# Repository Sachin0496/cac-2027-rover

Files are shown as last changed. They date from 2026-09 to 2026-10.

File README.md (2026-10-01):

# CAC 2027 Rover

Our entry for the Caterpillar Autonomy Challenge 2027 (Shaastra, IIT Madras): a small, light lunar-construction rover with a rotating bucket drum that crosses an
obstacle field, digs sand, carries it and builds a berm, first by remote control and then autonomously.

Start with [`CONTEXT.md`](CONTEXT.md): rules, scoring, strategy, budget, timeline, risks and the 2026-10-01 design review (section 17).

## Repository layout

```
CONTEXT.md        project context, shared by everything below
legacy-v1-v2/     the finished CAD-first designs (v1 and v2): CAD, docs, bill of materials
proto/            (next) the bare, minimal prototype: new work goes here, not in legacy-v1-v2/
firmware/         (next) ESP32 motor / encoder / sensor firmware
ros2_ws/          (next) ROS 2 Jazzy workspace
```

`proto/`, `firmware/` and `ros2_ws/` do not exist yet. Nothing outside `legacy-v1-v2/` depends on it, and nothing in it depends on them.

## Prototype direction

The prototype is deliberately minimal: bare chassis and drive, drum and lift, electronics mounted open, **no hood, side covers or other casings**. Casing was part of
the v2 design (hood, tray cover, side covers, handle); it adds mass and print time and hides the wiring we still need to debug. Add it back only after the
prototype digs, carries and dumps reliably.

## legacy-v1-v2/

Everything built so far lives in one folder so new work cannot tangle with it. Paths inside it are unchanged relative to each other.

| What | Where |
|---|---|
| v2 build guide, print list, mass and load paths | [`legacy-v1-v2/docs/v2-build-guide.md`](legacy-v1-v2/docs/v2-build-guide.md) |
| v2 priced order list and BOM | [`legacy-v1-v2/docs/v2-order-list.md`](legacy-v1-v2/docs/v2-order-list.md), [`legacy-v1-v2/hardware/bom_v2.csv`](legacy-v1-v2/hardware/bom_v2.csv) |
| What changed in v2 and where it departs from the plan | [`legacy-v1-v2/docs/v2-changelog.md`](legacy-v1-v2/docs/v2-changelog.md) |
| v2 parametric CAD (build123d), checks, STLs | `legacy-v1-v2/cad-v2/` |
| v1 CAD (OpenSCAD), build guide, BOM | `legacy-v1-v2/cad/`, [`legacy-v1-v2/docs/v1-build-guide.md`](legacy-v1-v2/docs/v1-build-guide.md), `legacy-v1-v2/hardware/bom.csv` |

### v2 at a glance

Four-wheel skid steer, drum digger on a lift arm. Stowed 601 x 478 x 445 mm, empty 7.94 kg, 74 % of the loaded weight on the front axle, BOM about INR 24.7k
(cap 25,000). It is a parametric Python model with scripted checks for collisions, mass, balance, printing, load paths and the competition rules.

```
cd legacy-v1-v2/cad-v2
uv venv --python 3.12 .venv && source .venv/bin/activate && uv pip install -r requirements.txt
python tasks.py check    # about 15 minutes on a laptop; prints ALL CHECKS PASS
python tasks.py all      # + STEP/STL export (needs FreeCAD), BOM, viewer, pictures, docs
```

`legacy-v1-v2/cad-v2/params.py` holds every dimension. Pictures are in `legacy-v1-v2/docs/img/v2/`.

### Design review, 2026-10-01

Reviewed against the 2027 problem statement. Fixed: the BOM had no wheel encoders (two encoder motors added), the ESP32's Wi-Fi/Bluetooth must be switched
off for the comms inspection, the 5 V converter was under-rated, and the score estimate was about twice too optimistic. See `CONTEXT.md` section 17 for these and
the bench tests still to do (dig depth, camera view, hazard-sensor blind zones, stall currents).

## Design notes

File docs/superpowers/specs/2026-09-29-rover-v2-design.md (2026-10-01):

# CAC 2027 rover v2 — design specification

Date: 2026-09-29 · Branch: `v2` · Status: approved in chat ("do it") and built through drop 3 (tags `v2-drop1` to `v2-drop3`). Where this document and the model disagree, the model wins; §16 is the as-built record and `docs/v2-changelog.md` lists every departure.

## 1. Purpose

Rover v1 (`cad/`, OpenSCAD) is a four-wheel skid-steer rover with a rotating bucket drum on a lift arm, for the Caterpillar Autonomy Challenge (CAC) 2027. v2 keeps that concept and re-engineers everything around it so that the machine

1. looks like a finished product, not a prototype;
2. can be built by students with a college 3D printer and hand tools, without drilling metal;
3. is verified by scripts (collisions, print fit, mass, balance, rules, load paths) instead of by eye.

The mission, rules, strategy, electronics and software plan in `CONTEXT.md` do not change.

## 2. Scope

**In scope:** every printed part; the mounting of every purchased part; the check suite; exports (STEP, STL, glTF, PNG renders, interactive viewer); BOM v2 and order list; build guide v2; v1→v2 change log; an update to `CONTEXT.md`.

**Out of scope:** firmware, ROS 2 and any software; wiring diagrams (only the physical mounting of electronics); URDF or simulation; suspension or tracks; a different motor family; finite-element analysis (hand calculations only); Blender renders; pushing to GitHub (only when the user says so). v1 stays untouched in `cad/`.

## 3. v1 baseline (measured from the repo)

| Fact | v1 |
|---|---|
| Printed part types (`cad/print.scad`) | 30 (the build guide says 29) |
| Printed mass (v1 `export.py` formula) | 2.57 kg |
| Heaviest single print | drum body, 490 g, about 20 h (≈ 25 g/h) |
| Metal to cut and drill | 4 tube lengths, about 30 holes, plus a cut plywood deck |
| Heat-set inserts | about 30 |
| Lift | 9 printed pieces plus an M8 rod with a printed thread |
| Wheel support | on the 6 mm gearbox shafts; outboard bearings optional |
| Front-axle share with a full drum | 80 % |
| Mass on the same accounting as v2 (§9.3) | about 7.0 kg (v1's own table says 7.5 kg: it double-counts the actuator clamp and uses 230 g wheels against 179 g in `export.py`) |
| STEP / FreeCAD | mesh-derived; the drum reports "invalid" in FreeCAD |
| Collision check | part groups, 4 arm poses, mesh based |
| Renders | flat-shaded OpenSCAD |

## 4. Acceptance criteria

"Flawless" means every row below passes at every drop (§11). Rows A1–A11 are enforced by scripts; A12 is a reviewed checklist.

| ID | Criterion | Requirement | Enforced by |
|---|---|---|---|
| A1 | Collisions | No two solids overlap by more than 1 mm³ at arm poses −25°, −20°, 0°, +20°, +35°. Every moving/static pair has at least 2 mm clearance over the whole −25…+35° sweep in 5° steps, except declared running fits (listed in `checks/interference.py` with their designed gap, minimum 0.4 mm). Mating features are modelled with clearance, so there is no allow-list for overlaps. | `checks/interference.py` |
| A2 | Valid solids | Every part is a valid closed solid; the exported STEP re-opens in FreeCAD 1.1 with 0 invalid shapes; every STL is watertight. | `checks/validity.py` |
| A3 | Print fit | Every printed part fits 210 × 210 × 240 mm (usable volume of a 220 × 220 × 250 printer) in its stated print orientation; every downward-facing surface steeper than 45° from vertical (outward normal with n_z below −0.707) either lies on the bed (z under 0.2 mm) or is a bridge whose smallest width is 8 mm or less; any other patch fails. So: no supports anywhere. | `checks/printfit.py` |
| A4 | Print effort | No single print above 180 g (about 7 h at v1's rate; v1's drum body is 490 g). Printed total is reported. | `checks/printfit.py` |
| A5 | Build effort | 0 drilled or tapped holes in metal; 0 heat-set inserts; the only metal cuts are four M4 tie rods to length (hacksaw). Extrusions are cut to length by the vendor (or by hacksaw, ±1 mm is fine). | BOM generator |
| A6 | Mass | Empty mass at most 8.0 kg (limit); goal 7.5 kg. Budget in §9.3. | `checks/massprops.py` |
| A7 | Balance | Front-axle share with a full drum (2.1 kg sand in the drum) at most 75 % (v1: 80 %); expected about 72 %. | `checks/massprops.py` |
| A8 | Rules | Stowed size at the carry pose at most 1500 × 750 × 750 mm; E-stop head at least 40 mm, with a clear approach (100 mm radius) from above, behind and both sides; energy-meter display facing within ±30° of rearward, centre at least 250 mm above ground; three arrow marks on upward-facing surfaces. | `checks/rules.py` |
| A9 | Sensor views | Camera cone (±35° horizontal, ±25° vertical) free of the rover's own parts at pan 0° and 180°; each ToF cone (27° full angle) free at the carry pose. | `checks/rules.py` |
| A10 | Load paths | Safety factor at least 2 at 3× the static load on: wheel housing and bolts, axle, pivot bracket, both arms, lift link, drum tie rods, tray plate (deflection ≤ 1 mm). Inputs and formulas are printed in the build guide. | `calcs.py` |
| A11 | Cost | BOM generated from the model, priced per item; goal ≤ ₹25k including filament (see §12: the estimate is ₹25.2k, so the order list names a cheaper acceptable substitute for the items that would close the gap). | BOM generator |
| A12 | Looks | The visual checklist in §8.4 passes on six fixed views at every drop. | manual review of renders |

## 5. Conventions

- Units mm, degrees, grams. World frame as v1: +X forward (drum end), +Y left, +Z up, ground at z = 0, frame centred on x = y = 0.
- Arm poses: press −25°, dig −20°, level 0°, mid +20°, carry/dump +35° (v1 values).
- Part ids are snake_case with a module prefix: `drv_`, `wheel`, `drum_`, `arm_`, `pivot_`, `lift_`, `tray_`, `batt_`, `tower_`, `hood_`, `body_`, `tof_`. Each part carries metadata: `kind` (printed / purchased / stock), `module`, `qty_per_rover`, `mass_g`, and for purchased parts `price_inr`, `price_basis` (listed / estimate), `source`, `datasheet` (true / measure-first).
- Printed mass = solid volume × 1.27 g/cm³ (PETG) × 0.75 (v1's factor for 3–4 walls and 25 % gyroid), so v2 and v1 are comparable.

## 6. Layout

All values live in `cad-v2/params.py`. Initial values below; constraints are enforced by the checks.

| Parameter | Initial value | Note |
|---|---|---|
| Wheel | Ø174 mm over grousers × 60 mm, 14 grousers | unchanged, so v1's sand-pit plan and numbers carry over |
| Track (wheel centre to centre) / wheelbase | 380 mm / 300 mm (axles at x = ±150, height 87 mm) | unchanged; overall width 440 mm |
| Rails | 2020 T-slot (20 × 20 mm, slot 6 mm, M5), centre line y = ±140 mm, z = 116…136 mm, x = −210…+170 mm (380 mm long) | if the front-corner clash below needs it, the rails rise by the smallest amount (expected ≤ 8 mm) |
| Cross members | 260 mm, butted between the rails; rear at x = −185, front at x = pivot_x − 65 (clears the arm roots by at least 5 mm at every pose) | joined with two inside corner brackets per joint |
| Arm pivot | pivot_x = 159 mm, z = 126 mm (v1: 199 mm) | 40 mm back gives about 72 % front-axle share on the §9.3 mass table (D4). The layout script keeps the largest shift between 20 mm (74 %) and 40 mm (72 %) for which the front-corner clash below is resolved by raising the rails by no more than 8 mm |
| Arm length, drum | 130 mm pivot to drum axis; drum shell Ø160, tooth tips Ø180, length 200 mm | unchanged |
| Lift | stroke at least 83 mm; T8×2 screw axis on the centre line, 155 mm above ground | |
| Tower | 2020 post 300 mm above the tray plate; overall height at most 620 mm (v1: 581 mm) | |
| Ground clearance | at least 60 mm under motors and mounts on firm ground | v1: about 70 mm |

**Front-corner clash (known):** with the pivot 40 mm back, the arm root at the front rail overlaps the front drive motor's gearbox by about 5 mm in z. The layout script resolves it by raising `rail_z0` (and with it the pivot) by the smallest amount that gives 5 mm clearance at every pose. If that needs more than 8 mm, the script reduces the pivot shift toward 20 mm; if 20 mm is still not enough, the fallback in §13 applies.

## 7. Modules

Six modules, each buildable and testable on its own. Mounting to the chassis is always M5 through round holes into spring T-nuts, with the printed part clamping on flat extrusion faces (nothing engages the slot), so slot differences between vendors do not matter.

### 7.1 Chassis (`modules/chassis.py`)

- **Stock (2020 T-slot, buy 2 × 1 m):** piece A = 380 + 380 + 232 mm (two rails, arm crossbar); piece B = 260 + 260 + 300 mm (two cross members, tower post). Total 1 812 mm.
- **Hardware:** 8 inside corner brackets (2 per joint), about 60 spring T-nuts M5, M5 button-head screws (10, 12 and 16 mm).
- **No plywood deck.** The electronics tray and the hood are the mounting surface.
- **Faces:** top slots carry tray, hood, battery cradle and tower base; outer slots carry the drive mounts; bottom slots carry the motor cradles; inner slots carry the pivot brackets.

### 7.2 Drive module ×4, identical (`modules/drive.py`)

Wheel loads go into two bearings; the motor shaft carries torque only.

- **Purchased (per module):** Johnson 12 V ~30 RPM side-shaft motor; 2 × 608 bearing; M8 × 80 hex bolt (axle); M8 nyloc nut and 2 washers; flexible jaw coupler 6→8 mm (Ø20 × 25 mm); 4 × M5 + T-nut (mount and cradle to rail); M4 bolts and nuts for the cradle.
- **Printed:** `drv_mount` (plate on the rail's outer face, with a two-bearing housing that reaches into the wheel's open inner side), `drv_cradle_roof`, `drv_cradle_cap`, `axle_spacer` (2 per module, one part type), `wheel` (hub and hex pocket for the bolt head are part of the wheel print; 165 g target, v1: 179 g).
- **Axle stack, outboard to inboard:** wheel (bolt head in the hex pocket) → outer spacer → bearing A → housing web → bearing B → inner spacer → washer and nyloc nut → flexible coupler → motor shaft. Tightening the nut clamps the bolt, wheel and both inner races into one rotating body; the housing shoulders and a printed retainer hold the outer races.
- **Motor position:** the gearbox axis sits 7.5 mm above the shaft (v1 convention; parameter `jm_shaft_off`, 0 for a centre-shaft motor). The cradle bolts to the mount through slotted M4 holes (±1.5 mm) so the shaft and axle can be aligned by eye with a straightedge; the coupler absorbs the rest.
- **Why:** a sideways skid loads the shaft through a wheel radius of 87 mm. On the gearbox bushing (span about 10 mm) that is roughly three times the reaction force of a 30 mm bearing span, and it is the failure mode v1's own guide worries about. Any motor with a 6 mm shaft also fits by sliding the cradle, which removes v1's dependence on unmeasured motor dimensions.

### 7.3 Excavator (`modules/excavator.py`, `modules/lift.py`)

- **Drum:** four rings of 48 mm between two 4 mm end plates (200 mm), shell 2.0 mm, four scoops per ring with the v1 baffle spiral (sweep 150°, core Ø52). Two ring designs, `drum_ring_a` and `drum_ring_b` (teeth rotated 45°), stacked A, B, A, B, so one tooth cuts at a time as in v1. Each ring has four external lugs at fixed angles (between the teeth, inside the tooth-tip envelope); four M4 tie rods (threaded rod cut to about 215 mm) clamp the stack with 8 nyloc nuts. End faces have a 2 mm spigot and recess for concentricity. Each ring is about 120 g (v1's one-piece body is 490 g).
- **End plates:** `drum_plate_drive` has a hex pocket for the M8 bolt head and a boss (the drum is driven through the same axle kit as the wheels); `drum_plate_idler` has a 608 pocket.
- **Arms:** `arm_drive` (left) carries the drum motor cradle and a boss with two 608 bearings; `arm_idler` (right) carries the idler bolt (M8 × 50, dead axle). Each arm has an integral square socket that clamps the 2020 crossbar (two M4 pinch bolts with nut traps) — no drilling. The arm root has a 608 bearing on an M8 × 50 pivot bolt held by `pivot_bracket_l` / `pivot_bracket_r`, which clamp on the rails' inner faces.
- **Lift:** T8 lead screw, single start, 2 mm lead (self-locking at a friction coefficient of 0.10 or more; dry brass on steel is 0.15–0.20), brass flange nut in `lift_carriage`, two identical `lift_bearing_block` (608), `lift_channel` (guide), `lift_cradle_roof` / `lift_cradle_cap` for a Johnson 300 RPM motor, the same flexible 6→8 mm coupler as the wheels, two micro limit switches, `lever` (clamped on the crossbar centre) and one `lift_link` (M5 pins). About 10 mm/s at 300 RPM. v1's two pushrods are replaced by one link on the centre line. At each arm pose the carriage position follows from the link length and lever geometry (closed form, as v1's `carriage_x`); the assembly builder derives it, and `interference.py` fails if the carriage would leave the screw's travel or the limit-switch positions.
- **Drum test jig (no new parts):** arms + crossbar + drum + drum motor on a 1 m length of T-slot as a handle; the build guide describes it for v1's "drum on a stick" test.

### 7.4 Electronics tray (`modules/electronics.py`)

- One removable **U-shaped tray** that rests on the rails and nests around the lift screw. Printed in three pieces (`tray_left`, `tray_right`, each at most 120 × 200 mm, and `tray_tie` behind the lift motor), joined by M4 bolts into one rigid unit before wiring. 3 mm plate with 6 mm ribs.
- **Left bay (power):** 4 × BTS7960 drivers, relay/contactor, main fuse and branch fuses, 5 V buck. **Right bay (compute):** Raspberry Pi 5 with cooler, ESP32, MPU6050, connectors to sensors and servo. A cable channel behind the lift motor joins the bays.
- **Battery cradle** (`batt_cradle`, strapped) on the rear cross member; default pack model 70 × 60 × 40 mm, ±3 mm adjustable.
- Every board sits on printed standoffs with slotted holes (±3 mm) so measured sizes can differ from the datasheet.

### 7.5 Sensor tower (`modules/tower.py`)

- 2020 post on the rear cross member with `tower_base` (4 × M5). Two-half cladding (`tower_sleeve_lower`, `tower_sleeve_upper`, wall 2 mm) hides the post and the cables.
- **Top:** `tower_camera_head` — USB webcam on an SG90 pan servo (0°/180°). **Side shelf below the camera line:** `tower_estop_shelf` — 22 mm panel-mount E-stop, modelled with a Ø60 mm head (any ≥ 40 mm head fits), set to the side so it never blocks the camera at either pan angle. **Rear face:** `tower_pzem_housing` — PZEM-051 display window facing back, high and visible. **Base:** `tof_rear_mount` (rear-looking ToF, 35° down).

### 7.6 Body (`modules/body.py`)

- Vented **hood** over the tray (about 200 × 300 mm) with a raised spine over the lift screw, in three panels printed upside down: `hood_left` and `hood_right` (105 mm wide) and `hood_spine` (90 mm wide), each at most 200 mm long, with the end walls built in. Seams are deliberate panel lines with a 0.6 mm reveal, never within 5 mm of a vent. Louvers face down and back to keep sand out; overlapping lips seal the seams. Fixed to the tray with M4 button screws.
- **Side covers** over the rails between the wheels (`body_side_cover`, mirrored), **ToF noses** (`tof_nose_l`, `tof_nose_r`) on the pivot brackets, one **carry handle** (`body_handle`, a bridge over the spine at the empty-mass centre of gravity, 30 mm hand clearance, bolted through the hood into the tray).
- **Three arrow marks**, each a 90 × 30 mm recess 0.8 mm deep on an upward-facing surface: forward on the front of the spine (pointing +x), length on `hood_left` (double-headed along x), width on the rear of the spine (double-headed along y). The size is an assumption; the rules digest gives none.

## 8. Design language

### 8.1 Colour by function

| Group | Colour | Used for |
|---|---|---|
| Working parts | CAT yellow `#FFCD11` | drum, arms, hood, tower head |
| Structure and drive | graphite `#2B2E33` | wheels, mounts, cradles, covers, trays, tower sleeves |
| Frame | natural aluminium `#C9CDD2` | 2020 extrusions |
| Hardware | steel `#8A8F98`, brass `#B5A642` | bolts, nuts, screw and nut |
| Electronics | black `#1A1A1A` | boards, motors, servo, camera |
| Safety | red `#D7191C` | E-stop only |

Colours are parameters in `params.py`; changing them regenerates everything.

### 8.2 Geometry rules

- External radius 3 mm on visible edges, 1.5 mm on small parts, 0.4 mm chamfer where a part meets the bed (elephant foot), 0.6 mm reveal between panels.
- Fastener heads sit in counterbores or hex pockets; no protruding nuts on visible faces; wiring hidden under the hood or in channels.
- The hood and tower share one vent-slot pattern on a 6 mm grid.
- Overhangs are designed in (45° chamfers, teardrop holes, stepped bridges), not left to supports.

### 8.3 Fastener policy

- Frame and mounts: M5 button head into spring T-nuts.
- Printed-to-printed: M4 socket or button head with a nut in a printed hex trap. **No heat-set inserts.**
- Pivots and axles: M8 bolts with nyloc nuts (the smooth shank runs in the bearings).
- Small parts (sensors, covers, switches): M3 with nut traps; self-tapping screws only for non-structural covers.
- Tools for assembly: 2.5, 3 and 4 mm hex keys and one 13 mm spanner (M8 bolts and nuts).

### 8.4 Visual review checklist (A12)

Six fixed views: front-left ¾, rear-right ¾, side at dig pose, front, top, exploded. Each drop must show: no floating or intersecting parts; all panel reveals equal; radii consistent; colours follow §8.1; no bolt sticking out of a visible face; E-stop, energy meter and camera each visible from at least one view; wheels and drum read as one family with the body.

## 9. Verification

Run with one command (`python tasks.py check`); a drop ships only when all checks pass.

### 9.1 Checks

- **`interference.py` (A1):** build the assembly at each pose; bounding-box prefilter, then exact boolean intersection volume for every candidate pair. Moving parts are the arm assembly (arms, drum, drum motor, crossbar, lever), the lift carriage and the link; wheels and the drum are checked as their swept cylinders (grouser-tip and tooth-tip radius). For the sweep, sample points on moving parts and measure the minimum distance to static parts.
- **`validity.py` (A2):** `is_valid` on every part; export the STEP; re-import it headless in FreeCAD 1.1 (`freecadcmd`) and check every shape; check each STL with trimesh for watertightness.
- **`printfit.py` (A3, A4):** place each part in its declared print orientation (`ORIENT` table), then check bounding box, downward-facing triangle areas past 45°, bridge spans, and mass by the §5 formula.
- **`massprops.py` (A6, A7):** mass and centre of gravity of the whole rover, empty and with 2.1 kg of sand at the drum centre, at the carry pose; front-axle share; overall size.
- **`rules.py` (A8, A9):** the geometric rules and cone checks in §4.
- **`calcs.py` (A10):** closed-form checks with the inputs printed. Loads: 3× the worst static wheel load (front axle at 75 %), lateral skid force 0.6 × vertical, drum reaction 60 N horizontal plus 40 N vertical at a tooth tip, the lift link force at the press pose. Material: PETG design stress 20 MPa along layers and 10 MPa across layers; steel bolts by class; brass and aluminium nominal.
- **`tests/`:** pytest on synthetic shapes proves each check catches what it should (an overlapping box pair, a 60° overhang, an oversize part, an unbalanced mass).

### 9.2 Fit-test kit (about 30 min print)

One STL that carries: three 608 seats (22.0, 22.1, 22.2 mm), M4 and M5 nut traps at three clearances, an M8 hex pocket (13 mm across flats) at three clearances, a hole set (M3, M4, M5, M8 at three clearances), and a 20 mm slice of the motor cradle. The user prints it first and sets three numbers in `params.py`: `tol_bearing`, `tol_trap`, `tol_hole`. Nothing large is printed before that.

### 9.3 Mass accounting and budget (grams, empty)

Printed parts by the §5 formula; purchased parts by datasheet or typical weight. v1 is recomputed on the same basis. Targets are for the drop-3 report.

| Item | v1 | v2 budget |
|---|---|---|
| Chassis extrusions and brackets (v1: tube and plywood deck) | 792 | 700 |
| Drive modules ×4, without motor and wheel | 344 | 820 |
| Wheels ×4 | 716 | 660 |
| Drive motors ×4 | 1 120 | 1 120 |
| Excavator without motor (drum, arms, pivots, crossbar, lever, hardware) | 1 057 | 1 111 |
| Drum motor | 280 | 280 |
| Lift (motor, screw drive, printed parts, link, switches) | 540 | 559 |
| Electronics boards and connectors | 390 | 390 |
| Tray and battery cradle | 247 | 240 |
| Battery pack | 250 | 250 |
| Sensor tower (post, cladding, E-stop, PZEM, camera, servo, ToF) | 653 | 699 |
| Body (hood, side covers, handle, ToF noses) | 0 | 410 |
| Wiring | 250 | 250 |
| Fasteners | 350 | 250 |
| **Total** | **≈ 6 990** | **≈ 7 740** |

The v2 budget is about 0.75 kg (11 %) above v1, which costs roughly a tenth of the mass-score component. The drivers are the bearing-supported drive modules (+0.48 kg) and the body (+0.41 kg). Goal 7.5 kg needs about 0.24 kg of lightweighting in drop 3 (thinner hood walls, lighter wheel spokes, lighter tower sleeves, lighter tray ribs); the hard limit is 8.0 kg.

v2 also prints more than v1: about 3.1 kg in roughly 40 part types (v1: 2.57 kg, 30 types), because of the hood, the tower cladding and the drive housings. Each new part is small; none exceeds 180 g, and the longest print falls from about 20 h to about 7 h.

## 10. Toolchain and repository layout

**build123d** (free Python library on the OpenCascade kernel that FreeCAD also uses), in a virtual environment inside `cad-v2/` (Python 3.12, a few hundred MB, nothing installed system-wide). Dependencies are pinned in `pyproject.toml` and mirrored in `requirements.txt`; `numpy`, `scipy`, `trimesh`, `pytest` for the checks. FreeCAD 1.1.3 (already installed; `/Applications/FreeCAD.app/Contents/Resources/bin/freecadcmd`) is used only to validate the STEP; Chrome (already installed) renders images headlessly.

```
cad-v2/
  pyproject.toml  requirements.txt  tasks.py     # tasks.py: check | export | render | all
  params.py                # every shared dimension, colour, tolerance
  lib/     profile2020.py  cots.py  fasteners.py  style.py
  modules/ chassis.py  drive.py  excavator.py  lift.py  electronics.py  tower.py  body.py
  assemble.py              # rover(pose) -> named, coloured, metadata-carrying compound
  checks/  interference.py  validity.py  printfit.py  massprops.py  rules.py
  calcs.py
  export.py                # STEP, STL in print orientation, glTF, BOM (json and csv)
  render/  viewer.html  render.py
  tests/
  out/                     # generated: rover_v2.step, stl/, rover_v2.glb
docs/v2-build-guide.md  docs/v2-order-list.md  docs/v2-changelog.md  docs/img/v2/
hardware/bom_v2.csv
```

To change a dimension: edit `params.py`, run `python tasks.py all`. The STEP, STLs, BOM, renders and checks all regenerate.

## 11. Deliverables and drops

Each drop is committed on branch `v2` and tagged (`v2-drop1`, `v2-drop2`, `v2-drop3`); all applicable checks pass before the tag.

| Drop | Contents | Why this order |
|---|---|---|
| **1 — mobility kit and order list** | The tooling (params, lib, checks, tests, export, render); chassis, four drive modules, four wheels; the fit-test kit; `hardware/bom_v2.csv` and `docs/v2-order-list.md` covering every purchased part whose spec is fixed by then (extrusions with cut lengths, motors, bearings, couplers, bolts, T-nuts, T8 screw, brass nuts) | The team orders parts around 5 Oct and the chassis must drive on sand around 20 Oct. |
| **2 — excavator** | Drum rings and plates, arms, pivot brackets, crossbar, lever, lift module; the balance study with the real model; calcs for arms, lift and drum; renders of dig, carry and dump; drum test-jig instructions | The drum print and pit test are the biggest unknown and come first. |
| **3 — electronics, tower, body, documents** | Trays, battery cradle, tower, hood, covers, handle, arrows, ToF noses; all checks on the full assembly; lightweighting pass; six fixed renders and an exploded view; the interactive viewer; final BOM; build guide; change log; `CONTEXT.md` update | Everything left, and the look is judged on the finished machine. |

Fastener counts in the order list are final at drop 3; the order list advises buying an assortment with 20 % spare until then.

**Planning:** one implementation plan per drop. The drop-2 and drop-3 plans are written after the previous drop's checks pass, because they depend on its geometry (for example how the front-corner clash resolves).

## 12. BOM and budget

Estimates use v1's sources and price basis (Indian store listings, 2026-09-28) for unchanged items; new items are estimates until priced during drop 1.

| Change against v1 | ₹ |
|---|---|
| Frame: T-slot 2 m (900), brackets (200), 60 spring T-nuts (480), M5 screws (120), minus tube and plywood (−800) | +900 |
| Drive modules: 10 more 608 bearings (350), six flexible couplers at ₹200 less v1's one rigid coupler at ₹100 (1 100), M8 × 80 axle bolts, nuts, washers (150) | +1 600 |
| Lift: T8×2 screw and brass flange nut in place of the M8 rod | +250 |
| Drum tie rods and nyloc nuts | +120 |
| No heat-set inserts | −300 |
| Filament 3.5 kg in place of 3 kg | +500 |
| **v1 ₹22 120 → v2** | **≈ ₹25 200** |

Excluding filament (the college may supply it) v2 is about ₹21 700. Substitutes that recover about ₹1 200 if needed: rigid couplers on the wheel axles (−₹400), less spare stock (−₹500), cheaper T-slot supplier (−₹300).

## 13. Risks, measure-first gates and fallbacks

| Risk | Mitigation or fallback |
|---|---|
| **M1: motor dimensions unmeasured** | Measure one Johnson motor before printing `drv_cradle_*`, `arm_*` motor cradles and `lift_cradle_*`; the fit-test kit includes a cradle slice; cradles slide ±1.5 mm. Fallback: motor family is a parameter block (`jm_*`). |
| **M2: sizes of PZEM-051, relay, buck, BTS7960, E-stop body and battery are unpublished or vary** | Defaults in `cots.py`; holders adjustable ±3 mm; measure when the parts arrive and update `params.py`. |
| Extrusion profile varies between vendors | Printed parts clamp on flat faces only; M5 through round holes into T-nuts. |
| Print tolerance varies between printers | Fit-test kit (§9.2). |
| Front-corner clash (arm root against front motor) | Raise the rails (≤ 8 mm). If more is needed: flip the motor offset on the front modules (ground clearance 60 mm) or lengthen the wheelbase to at most 340 mm (front axle forward); either is raised with the user first. |
| Balance target of 75 % not reachable | Report the achieved value; consider the wheelbase fallback above; no ballast (mass costs score). |
| Mass above 7.5 kg | Lightweighting list in drop 3; the user decides whether the 8.0 kg limit moves. |
| Lift screw back-drives (T8×2 is self-locking only above μ ≈ 0.09) | Lubricate; use the driver's brake mode; or fall back to v1's M8 rod with a printed nut. |
| build123d fillet or boolean failures | Build with simple operations; fillet before booleans; fall back to chamfers; per-feature try/except in the build so the failing feature is named. |
| Sand performance and drum torque | Not provable in CAD: the same measure-first pit tests as v1 (drum on a stick first). |

## 14. Decision log

| # | Decision | Reason | Rejected |
|---|---|---|---|
| D1 | Same concept: drum digger, four-wheel skid steer, same electronics | The user chose it; nothing to test a new concept against before the 10 Nov video | Polish only (capped by OpenSCAD); clean-sheet concept |
| D2 | 2020 T-slot frame with spring T-nuts, no plywood | No drilling; adjustable; hides vendor variation | 20 × 20 tube with drilled holes (about 0.3 kg lighter, harder to build) |
| D3 | Two-bearing axle module with flexible coupler for wheels and drum drive | Removes the sideways-skid load from the gearbox bushing and the dependence on motor dimensions | Wheels on gearbox shafts as in v1 (about 0.3 kg and ₹1 100 cheaper) |
| D4 | Arm pivot 20–40 mm back, battery and tower rearmost | Balance study on the §9.3 mass table (estimated positions): loaded front-axle share 77 % with no shift, 74 % at 20 mm, 73 % at 30 mm, 72 % at 40 mm, 70 % at 60 mm (v1: 80 %). The estimate is good to a few points, so the requirement is 75 % with about 72 % expected; the model's own mass report replaces the study at drop 2. | Ballast (mass costs score); a longer wheelbase (kept as a fallback) |
| D5 | Drum in two ring designs (A/B), four rings, external tie rods | Prints in about 5 h a ring instead of 20 h; a failed ring costs one ring; straight tie rods need fixed lug angles, so two designs rather than four identical rings | Four identical rings with rotating lugs (rods would not align) |
| D6 | T8×2 screw and brass nut, one link | Standard parts replace a printed thread; one link on the centre line | Commercial linear actuator (about ₹2 500 more) |
| D7 | build123d in a project venv | Real solids, fillets, true STEP, exact booleans for the checks | OpenSCAD (mesh STEP, no fillets) |
| D8 | Colour by function, CAT yellow and graphite | One family; the sponsor's colour; parameters | White/silver "lunar" or matte black (still possible: one line) |
| D9 | Pivot brackets clamp on the rail inner faces | Rails cannot be drilled across | Cross-drilled rail as in v1 |
| D10 | U-shaped tray in three pieces | A single tray cannot fit around the lift screw and the 220 mm bed | Two separate trays |

## 15. Assumptions and defaults

- Printer 220 × 220 × 250 mm, PETG, 0.4 mm nozzle; college supplies the printer.
- Hand tools, hex keys, a hacksaw, a soldering iron for electronics; no laser, CNC, lathe or drill press.
- Budget cap ₹25k including filament (`CONTEXT.md` §6); free tools only.
- 2020 T-slot is the B-type, slot 6 mm, M5. Spring T-nuts are M5 drop-in.
- Motor: Johnson 12 V side-shaft, Ø37 × 25 mm gearbox, Ø28.5 × 38 mm can, 6 mm D shaft (22 mm long, 5.5 mm across the flat), shaft offset 7.5 mm (v1 values, measure-first).
- Battery pack 3S2P about 70 × 60 × 40 mm, 250 g (measure-first).
- Arrow marks 90 × 30 mm (the rules digest gives no size).
- E-stop modelled Ø60 mm head, 22 mm panel-mount.
- Nothing is pushed to GitHub, and no artifact is published, without the user's explicit OK.

## 16. As built (2026-09-29)

All three drops are done; `python tasks.py check` prints ALL CHECKS PASS and the 120 tests pass.

| ID | Result |
|---|---|
| A1 | 0 collisions at the five poses (-28, -25, 0, +20, +35); 2 mm clearance moving-vs-static at eight poses from -28 to +35; no floating or half-held fastener (contact-graph check) |
| A2 | STEP re-opens in FreeCAD 1.1 with 438 solids and 0 invalid shapes; 44 STLs, all watertight |
| A3, A4 | every part fits 210 x 210 x 240 mm and prints without supports; largest print 137 g (limit 180); printed total 2.55 kg in 43 part types |
| A5 | 0 drilled or tapped holes, 0 heat-set inserts; the only cuts are the 2020 (three 1 m bars), one M4 rod (four tie rods) and one M8 rod (the lift screw) |
| A6 | 7.94 kg empty including the 250 g wiring allowance: inside the 8.0 kg limit, 0.44 kg over the 7.5 kg goal |
| A7 | front-axle share 74.1 % with 2.1 kg of sand at the carry pose (limit 75 %; v1 80 %); 53 % empty |
| A8 | stowed 601 x 478 x 445 mm; E-stop head 60 mm, reachable from above, behind and outboard; PZEM display faces rearward at 321 mm; three arrow plates on the roof |
| A9 | camera at pan 0 sees only the excavator, at pan 180 nothing; both front ToF cones and the rear cone are free at the carry pose |
| A10 | eleven load paths, lowest safety factor 2.1 (pivot bracket wall); tray plate deflects 0.88 mm at three times the load (limit 1 mm) |
| A11 | INR 23,329 with filament, wiring, sand pit and spares (cap 25,000; v1 22,120); `hardware/bom_v2.csv` |
| A12 | six fixed views plus dig, exploded and hood-off pictures in `docs/img/v2/`; reviewed by the author only, the user's eye is the real test |

Amendments to the decision log: D4's expected 72 % became 74 % (the excavator is heavier than budgeted; the rear axle moved 40 mm forward to compensate); D6 became an M8 x 1.25 rod
with two brass nuts and two link plates; D9's brackets stand on the rail tops instead of clamping on the inner faces; the hood is two halves, not three panels. See `docs/v2-changelog.md`.

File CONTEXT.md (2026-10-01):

# CAC 2027 Rover — Project Context

Single source of truth for the team (and for any AI assistant helping us).
Last updated: **2026-09-29** (v2 CAD added: see §10). Rules below are a summary of the official CAC 2027
problem statement — always check the latest PDF (links in §16) before relying on a number.

---

## 1. The challenge in one paragraph

The **Caterpillar Autonomy Challenge (CAC) 2027** is run by Shaastra (IIT Madras's tech fest)
and sponsored by Caterpillar. The rules are adapted from NASA Lunabotics. We build a
lunar-construction rover that starts at a random pose, crosses an obstacle field in a
sandbox, digs sand in the excavation zone, **carries** it (bulldozing is not allowed) and dumps
it into a berm target. Scoring = berm volume normalised by **robot mass** and **energy used**,
plus large bonuses for **autonomy**.

## 2. Key dates, prizes, team rules

| What | When |
|---|---|
| Registration closes (Unstop, free) | **30 Sep 2026, 00:00 IST** |
| Video round: working rover on sand (non-competitive, required) | 10 Oct – 10 Nov 2026 |
| Prelims at IIT Madras: 1 attempt, 10-min run | 2 Jan 2027 (tentative) |
| Finale: 1 attempt, 7-min setup, 15-min run, 5-min removal | 3 Jan 2027 (tentative) |

- **Prizes (₹3.5 L total):** Winner ₹1.25 L · 1st runner-up ₹95k · 2nd runner-up ₹70k ·
  Best Design ₹30k · Judges' Innovation ₹30k.
- **Team:** 1–12 students, any discipline, any college. Max **4** people in Mission Control
  (MCC) and max **4** in the arena for setup/removal. No faculty in the arena or MCC.
- **2026 results:** Winner Team Algo Steam (Sri Eshwar College of Engineering, also Best Design);
  runner-up Team Anveshak (IIT Madras); 2nd runner-up Team Rodix (KPR Institute).
  The organisers' 2027 resources guide says many 2026 teams **had trouble with mobility**.

## 3. Arena (from the 2027 diagram, which is "for reference only")

- ~9 m × 5 m box, ~30 cm of tilled, dry sand.
- **Start zone** (~2 m, top-left, no obstacles) → **Obstacle zone** (~5.5 m) →
  **Excavation zone** (~1.5 m wide strip at the far end).
- **Construction zone** ~2 m × 1.5 m at the bottom-left, next to the start zone;
  **berm target 1.25 m × 0.9 m**. ⇒ Every dig→dump cycle crosses the obstacle zone **twice**.
- Obstacle zone: **≥3 boulders** (30–40 cm diameter, random heights) and **≥3 craters**
  (up to 40–50 cm wide). Smaller boulders may also be in the excavation zone.
- Start position and heading are random (judges spin N/S/E/W). The robot must carry 3 marked
  arrows: length, width and a "forward" reference.

## 4. Robot rules that shape our design

- **Size/mass:** stowed ≤ 1.5 × 0.75 × 0.75 m (may deploy up to +1.75 m in height after the
  start). ≤ 80 kg including any beacons.
- **Banned:** GPS; compass/magnetometer (must be disabled and explained to judges); ultrasonic
  sensors; touch/bump sensors; pneumatic rubber tyres; air- or foam-filled tyres; hydraulics.
  Closed pneumatics only if fully self-contained.
- **No walls:** the robot must not use arena walls for sensing, mapping or collision avoidance,
  and we must prove it. Not disclosing the autonomy sensing method = disqualification.
- **No line-of-sight driving (new in 2027):** operators may only use data/video from the robot
  and the competition monitors.
- **Sand:** only from the excavation zone; must be carried (a small lift is enough). Don't touch
  rocks or cross craters in the obstacle zone (allowed in the excavation zone).
- **Penalties:** wall ram −50 (twice), 3rd ram cancels the run. The robot must move within
  5 min of the timer starting or the run ends.
- **E-stop:** unmodified off-the-shelf red mushroom button, ≥40 mm, twist/pull to reset, one per
  robot. One press must disconnect the battery from **all** controllers (a relay is fine if it
  fails open). An onboard computer may run on its own separate battery.
- **Energy logger:** off-the-shelf logger (organisers' example: PZEM-051) wired **between the
  battery and the E-stop**, mounted high and visible. Wrong wiring = −30 on BCP-energy.
- **Comms:** our own unmodified dual-band 802.11 router (2.4 GHz must be switchable off),
  assigned SSID, WPA2/3, no hidden SSID, 20 MHz channels on 2.4 GHz, no amplifiers; 5 GHz
  allowed. **Average link ≤ 4,000 kbps.** Organisers provide no Wi-Fi. No 2.4 GHz Zigbee;
  Bluetooth class 2/3 only. **Every** wireless device on the robot may only transmit on the
  assigned SSID: switch off the ESP32's Wi-Fi and Bluetooth in firmware (its default BT power
  is above the 2.5 mW class-2 limit), turn off the Pi's Bluetooth, and keep the Pi on 5 GHz.
- **Markers/beacons:** max 5 (all markers or all beacons) or 2 beacons + 3 markers. Placed on the
  start-zone frame (2 sides) plus one on the start-zone wall; not in the obstacle zone, berm
  zone, other walls, floor or ceiling. Markers ≤ 25 × 25 cm, ≤ 60 cm high, one tag per marker.
  Lasers Class I/II (<5 mW) with eye-safety documentation. The robot must detect and interpret
  markers onboard — no human-in-the-loop.
- **Autonomy mode:** "hands-free" — nobody touches any control device. Announce every start,
  end and failure of an autonomy attempt to the Mission Control Judge **before** doing it.

## 5. Scoring

| Component | Formula / points |
|---|---|
| BCP-mass | V (cm³ above grade, inside target) ÷ (run minutes × robot kg) **× 4.4** |
| BCP-energy | V ÷ (run minutes × Wh used) **× 1.5** |
| Arena cameras | none used = **+120** · first camera (≤60 s) = +60 · second = 0. Onboard cameras are free. |
| Autonomy | see table below |

Organisers' worked example: 77,551 cm³, 15 min, 66 kg, 36 Wh →
344.6 (mass) + 215.4 (energy) + 60 (one arena camera) + 75 (autonomy) = **695**.

| Autonomy tier | Points | Conditions |
|---|---|---|
| Excavation | 75 | **Every** dig autonomous; bucket out of the sand before returning to remote control |
| Dump | 50 | **Every** dump autonomous; hand over to the computer **before** entering the construction zone |
| Travel | 250 | Hands-free from the start zone → excavation zone → construction zone. −30 one-time contact penalty; −50 if attempted after an RC crossing ("breadcrumbs"); no "point and traverse" |
| Full, 1 cycle | 450 | From the run start: traverse, dig, return, dump. May switch to RC afterwards |
| Full, 2+ cycles | 600 | Whole run hands-free, ≥2 cycles, berm points scored. −30 per rock/crater contact (cap −90) |

The resources guide lists possible autonomy totals of 50, 75, 125, 250, 300, 375, 450 and 600,
so the lower tiers appear to stack (e.g. travel + dig + dump = 375). **Confirm with organisers.**

## 6. Our strategy (decided 2026-09-28)

- **Small, light rover (~8–12 kg).** Scoring divides by mass: 12 L of sand in a 15-min run from a
  10 kg robot ≈ 12,000 ÷ (15 × 10) × 4.4 ≈ **352 mass points** — about the same as the
  organisers' 66 kg example moving 77 L. **That 12 L is optimistic** (see §17): at 0.27 m/s with
  a 1.4 L drum a dig–dump cycle takes about 2.3–2.7 min, so a 15-min finale moves 5–6 L
  (≈ 150–250 mass points) and the 10-min prelims 3 L (≈ 130–185). The berm terms are therefore
  worth far less than the autonomy tiers (250–600) and the +120 for no arena camera: spend
  effort on reliable autonomy and mobility, not on shaving grams.
- **Budget ≤ ₹25k, v1 ≈ ₹22k** (≈ ₹19k if the college provides filament). Excludes the
  Raspberry Pis (we have several), a borrowed router, laptops, the college 3D printer and travel.
- **Excavator = rotating bucket drum** (research-backed, see `legacy-v1-v2/docs/v1-build-guide.md`): a light
  rover can't push a front bucket through sand, but a drum takes small bites, and one part
  digs, carries and dumps.
- **Autonomy ladder:** 125 (auto dig + dump) → 375 (+ travel) → **450** (one clean autonomous
  cycle at the run start, then remote control to build berm volume). Go for 600 only if
  practice runs show almost every full cycle succeeding.
- **Never use the arena cameras** (+120) → onboard video must be good enough to drive by.
- **Why not bank on 600:** reliability compounds. One cycle ≈ 10 steps; at 95% success per step a
  cycle succeeds ~60% of the time and two cycles ~36%. At 99% per step: ~90% and ~82%.
- **No VLM/LLM in the control loop.** The mission is a fixed script; use a state machine.
  There is no internet in MCC, so everything runs onboard.

## 7. System design

The v1 CAD model is in `legacy-v1-v2/cad/` (open `legacy-v1-v2/cad/rover.scad`); the build guide with cut, print and
hardware lists is `legacy-v1-v2/docs/v1-build-guide.md`.

### Mechanical (v1)
- 4-wheel skid steer on **Johnson 12 V geared motors, ~30 RPM** (torque first; ~0.27 m/s). The
  100 RPM version is only ~5.7 kg·cm, weak for loose sand. Motors hang under the rail corners in
  printed clamps that also tie each rail to its cross member.
- **3D-printed grouser wheels:** 174 mm over 14 grousers, 60 mm wide, directly on the D-shafts
  with the wheel load right at the gearbox face (outboard 608 bearings are an optional upgrade).
- **Bucket drum** on the front: 160 mm shell, 200 mm long, 8 scoops in two rings clocked 45°,
  internal spiral baffles, ~1.4 L usable. Spins ~30 RPM on a Johnson motor clamped in the left arm.
- **Lift:** two printed arms pivot on the rail ends; a lever and two pushrods connect them to a
  **printed lead-screw actuator** on the deck (M8 rod, ~300 RPM Johnson, ~6 mm/s, 83 mm stroke,
  self-locking). Arm −25° press / −20° dig / +35° carry.
- 20 × 20 aluminium tube frame (420 × 300), 6 mm plywood deck. Stowed 632 × 440 × 581 mm,
  ~7.5 kg empty (estimate), 80 % of the loaded weight on the front axle.
- Sealed printed electronics box, vented driver hood, dust covers.

### Electrical
```
3S Li-ion pack (≥20 A BMS) → PZEM-051 logger → E-stop (+ relay) → main fuse
    ├─ BTS7960 × 2 → drive motors (left side / right side)
    ├─ BTS7960 × 1 → drum motor
    ├─ BTS7960 × 1 → lift actuator motor
    └─ 5 V / 5 A buck → Raspberry Pi 5 → ESP32, sensors
```
- Powering the Pi from the main pack (after the logger) means **all** energy is logged — the
  simplest story at inspection. A separate Pi battery is allowed, but be ready to justify energy.
- Check the BMS current rating against the motors' stall currents; fuse every branch.

### Compute and sensors
- **Raspberry Pi 5 (4 GB)**; a second Pi can take the vision work if one is too slow.
- **ESP32** for motor PWM, encoders and limit switches (real-time jobs off the Pi).
- **1 USB webcam on an SG90 pan mount:** faces forward for driving, turns back to see AprilTags.
- **3 × VL53L1X laser ToF sensors** as the hazard detector: two on plates ahead of the front
  wheels looking 35° down the wheel tracks, one on the mast looking backwards for reversing.
  Rock = range shorter than flat ground; crater = range longer / no return. Class 1 laser →
  allowed (bring the datasheet). Use the XSHUT pins to give each sensor its own I²C address.
- **MPU6050 IMU** (6-axis, no magnetometer → nothing to explain for the compass rule).

### Software (Ubuntu 24.04 + ROS 2 Jazzy on the Pi 5)
- **Teleop:** joystick → `cmd_vel`; H.264 video via GStreamer at ~1–1.5 Mbps (inside the 4 Mbps cap).
- **Drivers:** ESP32 bridge (serial or micro-ROS), IMU, ToF, camera, `apriltag_ros`.
- **Localisation:** `robot_localization` EKF fusing gyro + wheel odometry + AprilTag fixes.
  Expect good fixes near the start/construction zones and dead-reckoning across the obstacle field.
  Rule of thumb (estimate): a 25 cm tag is detectable to ~5 m at 640×480 and ~8 m at 1280×720.
- **Hazards and planning:** ToF hazards on a ~10 cm grid of the known arena layout; A* or
  bug-style avoidance toward the goal. **Not** a fixed path — that is penalised.
- **Mission state machine:** LOCALISE → TRAVERSE → DIG → RETURN → ALIGN → DUMP → repeat.
  Every state gets a timeout and a recovery (back up, retry the dig, re-localise, or declare
  failure and hand over to RC).

## 8. Budget (v1 ≈ ₹22k) — full list in `legacy-v1-v2/hardware/bom.csv`

| Group | ₹ |
|---|---|
| 6 Johnson geared motors (4 drive + drum + actuator) | 3,000 |
| 4 BTS7960 motor drivers | 1,200 |
| Lift hardware (608 bearings, M8 rod and bolts, coupler, limit switches) | 570 |
| Fasteners + heat-set inserts | 700 |
| Aluminium tube (3 m) + plywood deck | 800 |
| 3 VL53L1X ToF sensors | 1,500 |
| USB webcam + SG90 pan servo | 1,150 |
| MPU6050 + ESP32 | 700 |
| 3S Li-ion pack (≥20 A BMS) + charger | 2,500 |
| E-stop, relay, fuses, connectors, wire, 5 V buck | 2,500 |
| PZEM-051 energy meter | 2,000 |
| ~3 kg PETG filament (v1 uses ~2.6 kg) | 3,000 |
| Practice sand pit + AprilTag prints | 1,000 |
| Spares | 1,500 |
| **Total** | **≈ 22,120** |

Prices marked "listed" in the CSV came from Indian store listings on 2026-09-28; everything else
is an estimate. The PZEM-051 is sold on Robu but its price wasn't visible.

## 9. 3D printing plan

- **Print:** 29 part types for v1 (list and quantities in `legacy-v1-v2/docs/v1-build-guide.md` §3; STLs in
  `legacy-v1-v2/cad/stl/`), all within a 220 × 220 mm bed and without supports. Also AprilTag stands
  (weighted bases, ≤60 cm).
- **Settings:** PETG (handles heat and knocks better than PLA), 3–4 walls, 20–25% gyroid infill;
  metal bolts as pivot pins; heat-set inserts wherever screws go into plastic.
- **Don't print:** the main load-bearing rails, the E-stop, the energy meter or the battery.
- The rules allow open honeycomb wheels as long as the edges aren't sharp. No foam.

## 10. CAD and tools

**Decision (2026-09-28): free tools only, no paid licences.**

- **OpenSCAD** (free) — the v1 model is written in OpenSCAD and is the editable master:
  `legacy-v1-v2/cad/rover.scad` (assembly), `legacy-v1-v2/cad/params.scad` (all shared dimensions), one file per
  subsystem. `check_interference.py` checks for collisions; `export.py` makes the STLs.
  Install on macOS: `brew install --cask openscad@snapshot` (the stable 2021 cask is disabled).
- **FreeCAD 1.1** (free, open-source, offline) — for viewing, measuring and new parts.
  `legacy-v1-v2/cad/rover_v1.FCStd` (and `rover_v1.step.zip` for other CAD) is generated from the OpenSCAD
  model by `export_freecad.py`; don't edit it by hand. Install: `brew install --cask freecad`.
- **Onshape (free Education plan)** — optional browser alternative if several people need to edit
  the same model at once; each person signs up with a student account.
- **v2 (2026-09-29): build123d, in `legacy-v1-v2/cad-v2/`.** Same concept, re-engineered: parametric Python CAD on the OpenCascade kernel (the one FreeCAD uses), scripted checks for every claim
  (`python tasks.py check`), B-rep STEP + watertight STLs, an interactive viewer (`legacy-v1-v2/cad-v2/out/rover_v2_viewer.html`). Guide: `legacy-v1-v2/docs/v2-build-guide.md`; ledger of changes: `legacy-v1-v2/docs/v2-changelog.md`;
  priced parts: `legacy-v1-v2/docs/v2-order-list.md` and `legacy-v1-v2/hardware/bom_v2.csv` (≈ ₹24.7k after the 2026-10-01 review). Empty mass 7.94 kg with a 250 g wiring allowance (v1 ≈ 7.0 kg on the same accounting), front-axle share 74 % with a full drum (v1 80 %).
  v1 in `legacy-v1-v2/cad/` is untouched. Print the fit-test kit (`legacy-v1-v2/cad-v2/out/stl/fit_test_kit.stl`) before anything else.
- **Day 1:** a 1:1 cardboard mock-up to check the envelope and component layout before CAD.
- Why bother with CAD: envelope inspection, printing, and the ₹30k Best Design Award.

## 11. Timeline

| By | Milestone |
|---|---|
| 29 Sep | **Register on Unstop** (closes 30 Sep 00:00 IST) |
| 5 Oct | Cardboard mock-up + CAD v1; order all parts; build the sand pit |
| 20 Oct | Chassis driving on sand by remote; 3–4 wheel variants tested |
| 10 Nov | Dig + carry + dump by remote, driving from onboard video only → **submit video** |
| 30 Nov | Autonomous dig + dump (125); AprilTag localisation; ToF hazard detection |
| 20 Dec | Travel autonomy → one full autonomous cycle (450); **hardware freeze** |
| 20 Dec – 1 Jan | ≥20 full mock runs with real setup/run/removal timings; pack spares and checklists |
| 2–3 Jan | Prelims + finale at IIT Madras |

## 12. Team roles

- **Mechanical (2–3):** chassis, wheels, bucket, actuator, printing.
- **Electrical (1–2):** power, E-stop, logger, wiring, motor drivers, ESP32 firmware.
- **Software (2–3):** ROS 2, teleop/video, localisation, hazard detection, state machine.
- **Ops lead:** runs mock runs and checklists, owns the rules and inspection, talks to the judges.

## 13. Risks and mitigations

| Risk | Mitigation |
|---|---|
| Rover bogs down in loose sand (the #1 problem flagged in 2026) | Wide grouser wheels, low-RPM motors, test in the pit from week 3, practise climbing out of a dug hole |
| Sand jams the actuator, bearings or motors | Sealed box, dust covers, lead-screw sleeve; clean after every session |
| Battery trips its BMS under load | ≥20 A BMS; measure stall currents; fuse each branch |
| Wi-Fi drops at the venue | Own router on 5 GHz; test with many phones nearby; keep video ≤1.5 Mbps |
| Failing inspection | E-stop and logger wired exactly per rules; ToF datasheet ready; written explanation of the autonomy sensing |
| Only one attempt per round | ≥20 timed mock runs; recovery behaviour in every state; spares kit |
| Localisation drift across the obstacle field | Re-localise on tags near start/construction; gyro-based heading; conservative speeds |
| ToF readings upset by sunlight or dust | Test in the actual lighting; shroud the sensors; have a camera-based fallback |

## 14. Open questions for the organisers

- May markers go anywhere other than the start-zone frame (e.g. the excavation zone)? The 2027
  list of banned zones doesn't mention it, but another rule limits them to the start-zone frame.
- ~~Prelims setup time~~ Answered by the 2027 problem statement: prelims 5 min setup / 10 min run / 5 min removal;
  finale 7 / 15 / 5. (The generic "10 minutes" in the MCC and beacon sections is the 2026 wording.) Five minutes
  must cover placing the robot, the tags and the Wi-Fi link-up: rehearse it.
- Where exactly are the construction zone and berm target in the **2027** arena diagram? The problem-statement text
  has no diagram; §3 relies on the diagram image. The 2026 diagram put the construction zone beside the excavation zone.
- Is the arena indoors or outdoors, and what is the lighting?
- Is a separately powered onboard computer (e.g. a Pi on its own battery) fine for energy accounting?
- Do the autonomy tiers stack exactly (e.g. travel + dig + dump = 375)?
- Stowed height: 0.75 m in 2027 (vs 1 m in 2026) — confirm.

## 15. Research notes and upgrade path (if budget grows later)

- **Stereo on a Jetson:** Lite Any Stereo V2 (Imperial, Jun 2026) — ~81–101 ms/frame on a Jetson
  Orin NX, code released ([paper](https://www.alphaxiv.org/abs/2606.24457),
  [code](https://github.com/TomTomTommi/LiteAnyStereo)). NVIDIA Fast-FoundationStereo
  (CVPR 2026) — near-FoundationStereo accuracy at 10× speed, in Isaac ROS
  ([paper](https://www.alphaxiv.org/abs/2512.11130),
  [code](https://github.com/NVlabs/Fast-FoundationStereo)).
- **Tiny single-camera depth:** ZipDepth (Bologna, Jul 2026, 6.1M params, 34 FPS on Orin NX; 40–45 FPS
  on a laptop CPU — the Pi 5 will be much slower, worth a test) ([paper](https://www.alphaxiv.org/abs/2607.08771)).
  DepthART (Trento, Jul 2026, 6M params, relative + metric) ([paper](https://www.alphaxiv.org/abs/2607.17099)).
- **Heavy models for offline labelling:** Depth Anything 3 ([paper](https://www.alphaxiv.org/abs/2511.10647));
  Sept 2026 survey ([paper](https://www.alphaxiv.org/abs/2609.01172)).
- **Real-world scale cheaply:** VL53L5CX 8×8 ToF + completion model (KAIST/Microsoft, Aug 2026)
  ([paper](https://www.alphaxiv.org/abs/2608.04737)); PTC-Depth — scale from robot motion
  ([paper](https://www.alphaxiv.org/abs/2604.01791)).
- **Terrain:** LuMon — craters are the worst case for every off-the-shelf depth model; retraining on
  your own terrain is what helps ([paper](https://www.alphaxiv.org/abs/2604.09352)).
  PIVOT — VLM used only as a slow fallback to geometric planning ([paper](https://www.alphaxiv.org/abs/2609.20983)).
- **Localisation:** MDE-VIO — small depth model + VINS-Mono on a Jetson AGX Orin, better in low
  texture ([paper](https://www.alphaxiv.org/abs/2602.11323)).
- **Cautionary:** ISRO SAC "Depth-Aware Rover" — UniDepthV2 on a Raspberry Pi 4 took ~7 s per frame;
  stereo calibration kept drifting ([paper](https://www.alphaxiv.org/abs/2604.22331)).
- **Open-source Lunabotics ROS 2 code to borrow from:**
  [College of DuPage](https://github.com/College-of-DuPage-Lunabotics/lunabot_ros),
  [UMN GOFIRST](https://github.com/GOFIRST-Robotics/Lunabotics),
  [Purdue](https://github.com/PurdueLunabotics/purdue_lunabotics).

## 16. Links

- [CAC 2027 on Unstop](https://unstop.com/competitions/caterpillar-autonomy-challenge-iit-madras-1744114)
- [CAC 2027 problem statement (PDF)](https://d8it4huxumps7.cloudfront.net/uploads/attachements/files/3e1cd352-c27c-4d90-b096-f7b5276f3654.pdf)
- [CAC 2027 resources guide and scoring matrix (PDF)](https://d8it4huxumps7.cloudfront.net/uploads/attachements/files/7b2240d9-b289-4a9a-83d5-0ac939919f50.pdf)
- [CAC 2026 rulebook (PDF)](https://cac.shaastra.org/assets/CATERPILLAR%20AUTONOMY%20CHALLENGE_2026-Bo_P5MoA.pdf)
- [Lunabotics mobility workshop (video)](https://youtu.be/bEcldIPXE5c)
- [NASA Lunabotics systems-engineering videos](https://www.attwaterconsulting.com/NASA%20Lunabotics%20Videos.html)

## 17. Design review, 2026-10-01 (against the 2027 problem statement and the 2026 rulebook)

Reviewed: the 2027 problem statement and resources guide, the 2026 rulebook, `CONTEXT.md`, the v2 build guide, changelog, `params.py`, `calcs.py`,
`checks/rules.py`, the drum, tower and BOM. Rules that changed from 2026 to 2027 are marked.

### Fixed in this commit
| # | Finding | Why it matters | Fix |
|---|---|---|---|
| 1 | **No encoders anywhere in the BOM**, yet §7 and the ESP32 line promise "encoders" and the EKF fuses "wheel odometry". The plain Robokits RKI-1156 has none. | No odometry across a 5 m obstacle field (gyro-only dead reckoning, ~0.5 m error after a minute), no speed control, so no straight driving on a skid-steer in sand. | BOM: two of the four drive motors become the Robokits 30 RPM quad-encoder Johnson (one per side, +INR 1,336). BOM is now INR 24,715 (cap 25,000). Re-measure `JM_CAN_LEN` when the motors arrive. |
| 2 | **ESP32 Wi-Fi/Bluetooth not addressed.** Rules: only the assigned SSID may transmit; Bluetooth only at class 2/3 (≤ 2.5 mW). An ESP32 powers up with both radios on. | A failed communications inspection means the robot does not enter the arena. | Firmware must call `esp_wifi_stop()` / `btStop()` (or build with both disabled); Pi: `dtoverlay=disable-bt`, 5 GHz only. §4 and the ESP32 BOM note updated. Be ready to show it at inspection. |
| 3 | **5 V converter spec was "LM2596/XL4015 class".** An LM2596 module is 3 A; the Pi 5, webcam, three ToF sensors and an SG90 share this rail, and motor-start dips come back through it. | Pi 5 brown-out or reboot mid-run, and the run is over (one attempt). | Spec: genuine 5 A part (XL4015 module or 5 V UBEC, INR 300), 1000 uF on its output, separate cap at the servo. Add `usb_max_current_enable=1` to the Pi's `config.txt`. |
| 4 | **Score expectation was ~2x optimistic** (12 L in 15 min). | Mis-sets priorities. | §6 now uses the cycle-time estimate below. |

### Findings that are not model changes (act on them while building)
- **The 8.0 kg limit and the 75 % front-axle share are our own targets, not rules** (the rule limit is 80 kg). The 55 g margin is therefore a score matter, not a compliance risk: 0.4 kg is about 5 % of the mass term (~10 points). Do not trade reliability for grams.
- **Cycle time.** 30 RPM x 174 mm wheels = 0.27 m/s. One dig–dump cycle is about 21 m of driving (78 s) + dig (~25 s) + dump and alignment (~35 s) = 2.3–2.7 min. Over the 15-min finale that is 5–6 cycles, about 5–8 L if the drum fills 1.0–1.4 L, so ≈ 150–250 mass points and ~20–30 energy points. Over the 10-min prelims it is 3 cycles. The autonomy tiers (250 / 450 / 600) and the +120 for no arena camera are worth more than the whole berm. Do not buy faster motors: torque on sand is the known problem.
- **Dig depth is the biggest mechanical unknown.** At the dig pose the teeth sit 4 mm below grade (press pose: 10 mm); dry sand cutting force is small, so torque is not the limit but depth is. Loose sand lets the wheels sink a little, which helps. Test in the sand pit before anything else: time to fill the drum, and whether the front wheels lift when pressing. If it digs too shallow, the cheap hedge is a lower press pose (more lift stroke, check the front motor clearance) rather than a bigger drum.
- **Camera view.** The webcam is at z = 445 mm on the rear mast, pointing level. With ±25 degrees vertical view its lowest ray reaches the ground about 0.95 m ahead of the mast, so the last ~40 cm in front of the drum is blind (the drum itself hides more). This is the only onboard view for teleoperation (no line of sight, arena cameras cost points). Tilt the camera mount about 15 degrees down (not modelled yet) and re-run `tasks.py check`; the pan-0 view check will then also see the hood roof, which is harmless, but update the check to allow it.
- **Hazard sensing.** Two ToF beams (27 degree cones) from the pivot brackets cover the width of the rover's path about 0.45 m ahead, which is adequate going straight but blind in turns and beside the wheels. Slow down and stop-scan before turning near an obstacle; each rock contact or crater crossing costs −30 (−20 in 2026, **changed in 2027**). Both ToF sensors look 20–25 degrees down and hit the sand within ~0.5 m, which is also the clean answer to the "walls may not be used for sensing" inspection question; cap ToF range in software at 1.5 m and log it.
- **Wall rams (−50 twice, third cancels the run) must be avoided without sensing the walls.** Build a keep-out margin of 0.5 m from the arena boundary into the planner, and make it larger after a long dead-reckoned stretch.
- **Battery vs stall current.** The BMS is 20 A; one Johnson 30 RPM stalls at several amps and there are six motors. A BMS trip is the same as an E-stop for the Pi. Wire each BTS7960 `IS` pin to an ESP32 ADC, ramp PWM, cut the drive on a stall (no motion with high current for 0.5 s) and limit the sum of motor currents in software to ~15 A. Measure the stall currents on the bench first.
- **Markers.** Only on the start-zone frame (2 sides) plus one on the start-zone wall, within 60 cm of the floor, ≤ 25 x 25 cm, one tag per marker, non-glare, maximum 5 (all tags), placed during the 5-minute prelims setup. Make clamp-on tag boards (printed clamps or tape-on plates) and practise placing them with two people in under 60 s. Tag range of ~5 m at 640 x 480 will not cover the whole arena: plan for dead reckoning (gyro + encoders) between the start and construction zones, and re-localise on every tag sighting. Calibrate the MPU6050 gyro bias for 5 s while stationary during setup.
- **Hands-free procedure.** In 2027 you must declare each autonomy attempt out loud to the Mission Control Judge before the robot starts, and a declared failure must be announced before resuming manual control. Nobody touches the laptop or controller during an attempt (E-stop is on the robot, so MCC cannot E-stop). Write the exact script and rehearse it.
- **Logger "highest practical location".** The PZEM sits at z = 321 mm below the camera head at 445 mm. The rules want it highest practical, so if a judge objects, swap the PZEM collar with the head collar (the mast carries 750 mm).
- **Mobility video.** The resources guide asks teams to check their design with the mobility equation from the Lunabotics workshop. Do that and keep the working in `legacy-v1-v2/docs/`: ground pressure here is only ~15 kPa per wheel (36 N over a 60 x 40 mm patch at the loaded front axle), so a light rover should pass, but the guide says many teams failed on mobility in 2026.

### What the model checks do and do not cover
Mass, balance, collisions at five poses, print rules, load paths, E-stop reach, PZEM view and the 750 mm height limit are scripted and pass (see `python tasks.py check`). Nothing scripted covers: encoders and wiring, radios, tag mounting, dig depth, drum retention of sand in the carry pose, sand ingress under the open belly, and the hazard-sensor blind zones above. These are on the bench-test list in §11.

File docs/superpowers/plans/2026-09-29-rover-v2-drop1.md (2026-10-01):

# Rover v2 — Drop 1 (tooling, chassis, drive modules, fit-test kit, order list) Implementation Plan

> **For agentic workers:** Use superpowers:executing-plans (inline) to implement this plan task by task. Steps use checkbox (`- [ ]`) syntax.

**Goal:** Build the `cad-v2/` toolchain and the first hardware: chassis, four drive modules with wheels, the fit-test kit, and the v2 order list, all passing the spec's checks.

**Architecture:** build123d (OpenCascade) parts are built in local frames, placed into an `Assembly` of `Item`s carrying metadata (kind, module, mass, colour, print orientation). Check modules consume the `Assembly`; `export.py` writes STEP/STL/GLB/BOM; `render/` bundles three.js and screenshots with headless Chrome.

**Tech Stack:** Python 3.12 (uv venv `cad-v2/.venv`), build123d 0.13, numpy, scipy, trimesh, pytest; FreeCAD 1.1.3 `freecadcmd` (STEP validation); Node + esbuild + three.js + Chrome headless (renders).

**Spec:** `docs/superpowers/specs/2026-09-29-rover-v2-design.md` (sections cited as §n).

## Global Constraints

- Units mm, degrees, grams; world +X forward, +Y left, +Z up, ground z = 0 (§5).
- Bed 210 × 210 × 240 mm; PETG 1.27 g/cm³ × 0.75; no print above 180 g (A3, A4).
- Overhang rule: downward faces with n_z < −0.707 must lie on the bed (z < 0.2) or be a bridge with smallest width ≤ 8 mm (A3).
- Collision: overlap ≤ 1 mm³ (A1). No allow-list for overlaps; mating features are modelled with clearance.
- No heat-set inserts, no drilled metal; M5 into spring T-nuts for frame joints, M4 + printed nut traps for printed joints (§8.3).
- Colours (§8.1): yellow `#FFCD11`, graphite `#2B2E33`, aluminium `#C9CDD2`, steel `#8A8F98`, brass `#B5A642`, black `#1A1A1A`, red `#D7191C`.
- Nothing is pushed to GitHub or published without the user's OK.
- Correction adopted from planning: the axle bolt is **M8 × 75** (spec text says 80) and the drive module has a printed **wheel cap** (hex pocket) and **three** spacer kinds (`axle_spacer_mid`, `axle_spacer_end` ×2); the spec is updated in Task 12.

## File Structure (cad-v2/)

| File | Responsibility |
|---|---|
| `params.py` | every shared dimension, colour, tolerance, derived axle-stack positions |
| `lib/model.py` | `Item`, `Assembly`, `to_bed()`, colour helper |
| `lib/profile2020.py` | 2020 T-slot profile solid `extrusion(length)` |
| `lib/fasteners.py` | `bolt`, `nut`, `washer`, `tnut` solids and hole cutters |
| `lib/cots.py` | purchased parts: motor, bearing 608, coupler, corner bracket |
| `checks/printfit.py` `validity.py` `interference.py` `massprops.py` | A2–A4, A1, A6/A7 |
| `modules/chassis.py` `drive.py` `fittest.py` | geometry |
| `assemble.py` | `rover(pose)` → `Assembly` |
| `export.py` `tasks.py` | STEP/STL/GLB/BOM; CLI `check|export|render|all` |
| `render/` | `scene.js`, `build.mjs`, `render.py` |
| `tests/` | pytest for every module above |

---

### Task 1: Scaffold and smoke test

**Files:** Create `cad-v2/pyproject.toml`, `cad-v2/requirements.txt`, `cad-v2/tests/test_smoke.py`; Modify `.gitignore`.

- [ ] **Step 1:** Write `pyproject.toml` (`[tool.pytest.ini_options] testpaths=["tests"]`, `pythonpath=["."]`) and `requirements.txt` from `.venv/bin/python -m pip freeze` restricted to build123d, numpy, scipy, trimesh, pytest, networkx, rtree (pinned).
- [ ] **Step 2: Failing test** `tests/test_smoke.py`:

```python
from build123d import Box, Cylinder, Pos, export_step
def test_build123d_roundtrip(tmp_path):
    p = Box(20, 20, 20) - Pos(0, 0, 0) * Cylinder(5, 30)
    assert p.is_valid and abs(p.volume - (8000 - 3.14159265 * 25 * 20)) < 1
    export_step(p, str(tmp_path / "t.step")); assert (tmp_path / "t.step").stat().st_size > 1000
```
- [ ] **Step 3:** `cd cad-v2 && .venv/bin/python -m pytest -q` → PASS (env exists from the spike).
- [ ] **Step 4:** Append to `.gitignore`: `cad-v2/.venv/`, `cad-v2/render/node_modules/`, `cad-v2/out/*.glb`. Commit `chore(cad-v2): scaffold`.

### Task 2: Core model (`lib/model.py`, `params.py`)

**Interfaces — Produces:**
`Item(id, part, kind, module, shape, color, mass_g=None, moving=None, local=None, orient=None, meta={})`;
`Assembly.add(item)->Item`, `.items`, `.by_module(m)`, `.compound()->Compound`; `to_bed(shape)->shape` (translate so min z = 0, centred on bbox XY); `printed_item(id, part, module, local, place, color, orient=None, **meta)->Item` (shape = `place * local`).

- [ ] **Step 1: Failing tests** `tests/test_model.py`:

```python
from build123d import Box, Pos
from lib.model import Assembly, printed_item, to_bed
def test_to_bed_sits_on_z0():
    s = to_bed(Pos(5, 5, 50) * Box(10, 10, 10))
    bb = s.bounding_box(); assert abs(bb.min.Z) < 1e-6 and abs((bb.min.X + bb.max.X) / 2) < 1e-6
def test_assembly_compound_labels_and_colors():
    a = Assembly(); a.add(printed_item("m1", "mount", "drive", Box(1, 1, 1), Pos(0, 0, 0), "#FFCD11"))
    c = a.compound(); assert [ch.label for ch in c.children] == ["m1"]
def test_duplicate_id_rejected():
    import pytest; a = Assembly(); it = printed_item("x", "p", "m", Box(1, 1, 1), Pos(0, 0, 0), "#000000"); a.add(it)
    with pytest.raises(ValueError): a.add(it)
```
- [ ] **Step 2:** run → FAIL (module missing). **Step 3:** implement `lib/model.py` (dataclass `Item`; `Assembly` with dict for uniqueness; `compound()` sets `shape.label=id`, `shape.color=Color(hex)`; `printed_item` copies `local` with `place * local`, stores `meta`). **Step 4:** write `params.py` with constants in the table below. **Step 5:** run → PASS; commit `feat(cad-v2): core model and params`.

`params.py` values (all initial per §6): `TUBE=20`, `RAIL_X0=-210`, `RAIL_LEN=380`, `RAIL_Y=140`, `RAIL_Z0=116`, `CROSS_LEN=260`, `PIVOT_X=159`, `CROSS_FRONT_X=PIVOT_X-65`, `CROSS_REAR_X=-185`, `AXLE_X=150`, `AXLE_Z=87`, `WHEEL_D=174`, `WHEEL_W=60`, `WHEEL_IN_Y=160`, `WHEEL_OUT_Y=220`, `JM_GEAR_D=37`, `JM_GEAR_LEN=25`, `JM_CAN_D=28.5`, `JM_CAN_LEN=38`, `JM_SHAFT_D=6`, `JM_SHAFT_FLAT=5.5`, `JM_SHAFT_LEN=22`, `JM_SHAFT_OFF=7.5`, `B608_D=22.0`, `B608_W=7.0`, `TOL_BEARING=0.2`, `TOL_TRAP=0.4`, `TOL_HOLE=0.4`, colours dict, and the derived **axle stack** (y measured outward from the frame centre, left-side module): `Y_GEAR_FACE=123.4`, coupler `133.6..158.6`, nut `158.6..166.6`, washer `166.6..168.2`, `axle_spacer_end` `168.2..170.7`, bearing B `170.7..177.7`, `axle_spacer_mid` `177.7..200.3`, bearing A `200.3..207.3`, `axle_spacer_end` `207.3..209.8`, wheel boss `209.8..220`, wheel wall `216..220`, cap `220..228`, bolt head underside `222.5`, bolt tip `147.5` (M8 × 75).

### Task 3: Checks — printfit and validity

**Interfaces — Produces:** `checks.printfit`: `BED`, `FILL`, `PETG`, `MAX_PRINT_G`, `printed_mass_g(shape)->float`, `overhang_patches(shape, limit_deg=45)->list[dict(area, min_width, z_min)]`, `check_oriented(name, shape)->list[str]`, `check_assembly(asm)->list[str]`. `checks.validity`: `check_valid(asm)->list[str]`, `stl_watertight(path)->bool`, `freecad_step_check(step)->tuple[int,int]` (solids, invalid) via `freecadcmd`.

- [ ] **Step 1: Failing tests** `tests/test_printfit.py`:

```python
from build123d import Box, Cylinder, Pos, Rot
from checks.printfit import printed_mass_g, overhang_patches, check_oriented
def test_mass_formula():  # 10 mm cube: 1 cm3 * 1.27 * 0.75
    assert abs(printed_mass_g(Box(10, 10, 10)) - 0.9525) < 1e-3
def test_flat_part_on_bed_has_no_overhang():
    assert overhang_patches(Pos(0, 0, 5) * Box(50, 50, 10)) == []
def test_wide_ceiling_is_flagged_and_narrow_bridge_is_not():
    tbl = Pos(0, 0, 20) * Box(40, 40, 3) + Box(4, 4, 20).moved(Pos(-18, -18, 10).location) \
        + Box(4, 4, 20).moved(Pos(18, 18, 10).location)
    bad = [p for p in overhang_patches(tbl) if p["min_width"] > 8]; assert bad
    bridge = Pos(0, 0, 5) * Box(30, 6, 3) + Pos(-14, 0, 2.5) * Box(2, 6, 5) + Pos(14, 0, 2.5) * Box(2, 6, 5)
    assert all(p["min_width"] <= 8 for p in overhang_patches(bridge))
def test_45_degree_chamfer_ok_60_degree_flagged():
    wedge = lambda h: Pos(0, 0, 0) * Box(40, 40, 5) + Pos(0, 0, 0) * Box(1, 1, 1)
    assert check_oriented("ok", Pos(0, 0, 5) * Box(100, 100, 10)) == []
def test_oversize_and_light_limits():
    assert any("bed" in m for m in check_oriented("big", Pos(0, 0, 5) * Box(250, 10, 10)))
    assert any("g" in m for m in check_oriented("heavy", Pos(0, 0, 100) * Box(200, 200, 200)))
```
- [ ] **Step 2:** run → FAIL. **Step 3: Implement** `printfit.py`: tessellate (`shape.tessellate(0.05, 0.1)`), numpy triangle normals/areas; select triangles with `n_z < -0.7071` and `min z > 0.2`; connected patches via shared vertex ids (`scipy.sparse.csgraph.connected_components`); per patch `area`, `min_width = min(bbox_x, bbox_y)`, `z_min`; `check_oriented` reports (a) bbox beyond `BED` (sorted XY compared), (b) patches with `min_width > 8`, (c) mass above `MAX_PRINT_G`. `validity.py`: `is_valid` per item; `stl_watertight` via `trimesh.load(...).is_watertight`; `freecad_step_check` runs `/Applications/FreeCAD.app/Contents/Resources/bin/freecadcmd cad-v2/checks/fc_check.py <step>` and parses `FC_RESULT solids=N invalid=M` (the script from the spike is saved as `checks/fc_check.py`). **Step 4:** run → PASS; fix test 4 to build a real 60° wedge with `Box` rotated and assert it is flagged while a 45° one is not. **Step 5:** commit `feat(cad-v2): printfit and validity checks`.

### Task 4: Checks — interference and mass properties

**Interfaces — Produces:** `checks.interference`: `TOUCH_MM3=1.0`, `RUNNING_FITS: dict[frozenset[str], float]`, `overlap_volume(a,b)->float`, `find_collisions(asm)->list[tuple[str,str,float]]` (bbox prefilter, exact `a & b`, skips pairs of the same `part` group flagged `meta["group"]` equal), `min_clearance(asm, moving_ids, static_ids)->float`. `checks.massprops`: `mass_properties(asm, sand_g=0.0, sand_at=None)->dict(mass_g, cg=(x,y,z), front_share)` with front share from axle x = ±`AXLE_X`.

- [ ] **Step 1: Failing tests** `tests/test_interference.py`, `tests/test_massprops.py`:

```python
from build123d import Box, Pos
from lib.model import Assembly, printed_item
from checks.interference import find_collisions
from checks.massprops import mass_properties
def asm_of(*boxes):
    a = Assembly()
    for i, b in enumerate(boxes): a.add(printed_item(f"b{i}", "p", "m", b, Pos(0, 0, 0), "#000000"))
    return a
def test_overlap_found_touch_ignored():
    assert find_collisions(asm_of(Box(10, 10, 10), Pos(5, 0, 0) * Box(10, 10, 10)))
    assert find_collisions(asm_of(Box(10, 10, 10), Pos(10, 0, 0) * Box(10, 10, 10))) == []
def test_mass_cg_and_front_share():
    a = Assembly(); a.add(printed_item("f", "p", "m", Pos(150, 0, 50) * Box(10, 10, 10), Pos(0, 0, 0), "#000000"))
    a.items[0].mass_g = 100.0
    r = mass_properties(a); assert abs(r["cg"][0] - 150) < 1e-6 and abs(r["front_share"] - 1.0) < 1e-6
    r2 = mass_properties(a, sand_g=100.0, sand_at=(-150, 0, 50)); assert abs(r2["front_share"] - 0.5) < 1e-6
```
- [ ] **Step 2:** run → FAIL. **Step 3:** implement both (mass of an `Item`: `mass_g` if set else `printed_mass_g(shape)`; front share = `(cg_x + AXLE_X) / (2 * AXLE_X)`). **Step 4:** run → PASS. **Step 5:** commit `feat(cad-v2): interference and mass checks`.

### Task 5: Library — 2020 profile, fasteners, purchased parts

**Interfaces — Produces:** `profile2020.extrusion(length)->Part` (axis +Z, centred on origin, z from 0..length; 20 × 20, slot 6.2 wide, lip 1.8, T-cavity 11 wide × 4.6 deep, centre bore Ø4.2); `fasteners.bolt(d, length, head="button"|"hex"|"socket")->Part` (axis +Z, head under z = 0, shank z 0..length); `nut(d, nyloc=False)`, `washer(d)`, `tnut()` (10 × 10 × 4 with Ø5 hole; along Z); `cots.motor_johnson(offset=JM_SHAFT_OFF)->Part` (shaft axis = +Y, shaft axis at origin, shaft pointing +Y; gear face at y = 0; gearbox axis +Z of shaft by `offset`), `cots.bearing_608()` (axis +Y, y 0..7), `cots.coupler_6_8()` (axis +Y, y 0..25, Ø20), `cots.corner_bracket()` (20 mm tall L). Each returns a shape with `meta` filled by `item(...)` helper: `mass_g`, `price_inr`, `price_basis`, `source`, `datasheet`.

- [ ] **Step 1: Failing tests** `tests/test_lib.py`: `extrusion(100).volume` within 300–360 mm²×100 (profile area between 300 and 360 mm²); `.is_valid`; `bolt(5, 10).bounding_box().size.Z ≈ 10 + head`; `bearing_608()` has bore Ø8 (an Ø8 pin `Cylinder(4, 20)` fits with zero overlap volume < 1 mm³); `coupler_6_8()` accepts an Ø8 pin from one end and an Ø6 pin from the other (overlap < 1 mm³); `motor_johnson()` gearbox axis at z = +7.5 relative to the shaft; masses set (motor 280 g, bearing 12 g, coupler 20 g).
- [ ] **Step 2:** run → FAIL. **Step 3:** implement (profile via `BuildSketch` rectangle minus four slot+cavity shapes and centre hole, extruded). **Step 4:** run → PASS. **Step 5:** commit `feat(cad-v2): library parts`.

### Task 6: Chassis module (`modules/chassis.py`)

**Interfaces — Consumes:** `profile2020.extrusion`, `cots.corner_bracket`, `fasteners.bolt/tnut`. **Produces:** `chassis.build(asm)->None` adding items: `rail_l`, `rail_r` (x −210..+170, y ±140, z 116..136), `cross_rear` (x −185), `cross_front` (x `CROSS_FRONT_X`), each `kind="stock"`, module `chassis`, colour aluminium; 8 `bracket_*` (two per joint, on the rail inner face either side of each cross member) with their M5 screws and T-nuts (`kind="purchased"`).

- [ ] **Step 1: Failing tests** `tests/test_chassis.py`: assembly has the 4 extrusions with lengths (380, 380, 260, 260) from bbox; rails' outer faces at |y| = 150; cross members end exactly at the rails' inner faces (|y| = 130, gap < 0.01); `find_collisions(asm) == []`; total extrusion length = 1 280 mm; 8 brackets; each bracket's screws have a matching T-nut (count equal).
- [ ] **Step 2:** run → FAIL. **Step 3:** implement. **Step 4:** run → PASS. **Step 5:** commit `feat(cad-v2): chassis`.

### Task 7: Drive module and wheel (`modules/drive.py`)

**Interfaces — Produces:** `drive.build(asm, x, side)` with `x ∈ {+150, −150}`, `side ∈ {+1, −1}` (left = +1): the left-front geometry is built once in a local frame (origin at axle centre, +Y outward) and placed by `Pos(x, 0, 0)` for left and `Rot(0, 0, 180)` about the frame centre for right (so all four modules use the same STL). Printed part types: `drv_mount`, `drv_cradle_roof`, `drv_cradle_cap`, `axle_spacer_mid`, `axle_spacer_end`, `wheel`, `wheel_cap`; purchased per module: motor, 2 × 608, M8 × 75 hex bolt, M8 nyloc nut, M8 washer, coupler, 4 × M5 button + T-nut, 2 × M4 × 35 + nuts (cradle), 4 × M4 × 20 + nuts (wheel cap).

Construction (local frame, mm; axle axis along +Y through x = 0, z = `AXLE_Z`):
| Part | Construction |
|---|---|
| `drv_mount` | plate x ±32, z 60..136 (R6 corners), y 150..160; housing Ø36 y 160..207.3; bore Ø(22+`TOL_BEARING`) y 150..177.7 (rear seat), Ø14 y 177.7..200.3 (web), Ø(22+`TOL_BEARING`) y 200.3..207.3 (front seat); two M5 holes Ø5.5 at x ±20, z 126 with Ø9.6 × 3 counterbore from y = 160; prints plate-down, housing up |
| `drv_cradle_roof` | x ±38, y 96..124, z 108..116; saddle Ø37.4 about the gearbox axis (z = 94.5) cut from below; two M5 obround slots 5.5 × 10 (long along y) at x ±32; two hex nut traps (M4, `TOL_TRAP`) in the leg bottoms at x ±19 (open on the mating face z = 108); prints rail face down |
| `drv_cradle_cap` | x ±25, y 96..124, z 73..108 with the same saddle from above; two Ø4.4 holes at x ±19; prints mating face up, no counterbore |
| `axle_spacer_mid` | tube Ø11 / Ø8.4, length 22.6 |
| `axle_spacer_end` | tube Ø11 / Ø8.4, length 2.5 |
| `wheel` | rim shell Ø154 × 3 mm wall, y 160..220; 14 grousers 10 mm tall × 3 mm thick on Ø154, full width; outer wall 4 mm (y 216..220) with six spoke openings and a central hole Ø8.4; hub boss Ø30, y 209.8..216 plus wall; four M4 nut traps on the boss end face at radius 15 (open on y = 209.8); 12 radial ribs 3 mm thick from boss to rim, 20 mm high; prints outer face down |
| `wheel_cap` | disc Ø44 × 8 (y 220..228), hex pocket 13 + `TOL_TRAP` AF × 5.5 deep from y = 228, Ø8.4 through hole, four Ø4.4 holes at radius 15; prints outer face up |

- [ ] **Step 1: Failing tests** `tests/test_drive.py`:

```python
from build123d import Box
from lib.model import Assembly
from checks.interference import find_collisions
from checks.printfit import check_oriented
from modules import chassis, drive
def full():
    a = Assembly(); chassis.build(a)
    for x in (150, -150):
        for s in (1, -1): drive.build(a, x, s)
    return a
def test_no_collisions():
    assert find_collisions(full()) == []
def test_wheels_touch_ground_and_width():
    a = full(); w = [i for i in a.items if i.part == "wheel"]; assert len(w) == 4
    for it in w:
        bb = it.shape.bounding_box(); assert abs(bb.min.Z) < 0.6 and abs(bb.size.Z - 174) < 1
def test_four_modules_share_one_stl_shape():
    a = full(); m = [i for i in a.items if i.part == "drv_mount"]; assert len(m) == 4
    v = [round(i.local.volume, 3) for i in m]; assert len(set(v)) == 1
def test_printed_parts_pass_printfit():
    a = full(); seen = set()
    for it in a.items:
        if it.kind == "printed" and it.part not in seen:
            seen.add(it.part); assert check_oriented(it.part, it.orient * it.local if it.orient else it.local) == [], it.part
def test_axle_stack_lengths():
    from params import Y_STACK; assert abs(Y_STACK["bearing_A"][1] - Y_STACK["bearing_A"][0] - 7) < 1e-6
def test_gearbox_clear_of_rail_and_ground_clearance():
    a = full(); g = [i for i in a.items if i.part == "motor"]
    for it in g: assert it.shape.bounding_box().min.Z >= 60
```
- [ ] **Step 2:** run → FAIL. **Step 3:** implement `drive.py` part by part, running the tests after each part (mount, roof, cap, spacers, cap, wheel). **Step 4:** run until PASS; fix collisions by adjusting dimensions in the table above, never by weakening a test. **Step 5:** commit `feat(cad-v2): drive module and wheel`.

### Task 8: Fit-test kit (`modules/fittest.py`)

**Interfaces — Produces:** `fittest.build()->Part` (one plate 150 × 60 × 4 with: three 608 seats Ø22.0/22.1/22.2 × 5 deep, M4 and M5 nut traps at `TOL_TRAP` −0.2/0/+0.2, an M8 hex pocket 13 mm AF at −0.2/0/+0.2, hole set M3/M4/M5/M8 at three clearances, and a 20 mm slice of the motor cradle saddle Ø37.4).

- [ ] **Step 1: Failing test:** valid solid; bbox ≤ 150 × 60 × 24; `check_oriented("fittest", shape) == []`; mass < 40 g. **Step 2:** run → FAIL. **Step 3:** implement (features cut from the top face so nothing bridges). **Step 4:** PASS. **Step 5:** commit `feat(cad-v2): fit-test kit`.

### Task 9: Assembly and check runner

**Interfaces — Produces:** `assemble.rover(pose=35)->Assembly` (drop 1: chassis + 4 drive modules; `pose` accepted and stored); `tasks.py check` runs validity, printfit, interference, massprops and prints a table; exit code 1 on any failure.

- [ ] **Step 1: Failing test** `tests/test_assemble.py`: `rover()` returns items for modules `chassis`, `drive`; `run_checks(rover())` returns no failures. **Step 2:** FAIL. **Step 3:** implement `assemble.py` and `tasks.py` (argparse subcommands). **Step 4:** `cd cad-v2 && .venv/bin/python tasks.py check` → all OK, PASS tests. **Step 5:** commit `feat(cad-v2): assembly and check runner`.

### Task 10: Export

**Interfaces — Produces:** `export.export_all(asm, out)`: `out/rover_v2.step` (labelled, coloured), `out/stl/<part>.stl` per printed part type in print orientation (`to_bed`, tolerance 0.05, angular 0.1), `out/rover_v2.glb`, `hardware/bom_v2.csv` generated from item metadata (columns as v1: `item,qty,unit_price_inr,total_inr,price_basis,source,purchase_status,notes`), and a printed-parts table (part, qty, size, grams).

- [ ] **Step 1: Failing test:** after `export_all(rover(), tmp)`, STEP exists and `freecad_step_check` returns `invalid == 0`; one STL per printed part type, each watertight; BOM total equals the sum of rows; glb size > 10 kB. **Step 2:** FAIL. **Step 3:** implement. **Step 4:** PASS. **Step 5:** commit `feat(cad-v2): exports and BOM`.

### Task 11: Render pipeline, renders and visual review (A12)

**Files:** `render/package.json`, `render/scene.js`, `render/build.mjs` (esbuild IIFE bundle + inline GLB as base64 into `out/rover_v2_viewer.html`), `render/render.py` (`python tasks.py render` → PNG per named view via headless Chrome `--screenshot`).

- [ ] **Step 1:** `scene.js`: GLTFLoader, `RoomEnvironment` at intensity 0.35, hemisphere + key directional light with soft shadow, ACES tone mapping exposure 0.9, OrbitControls, `window.setView(name)` for `front_left`, `rear_right`, `side`, `front`, `top`, `iso_low`. **Step 2:** build, then render the six views of drop 1 to `docs/img/v2/drop1_*.png`; open each PNG and check §8.4 (no floating parts, equal reveals, radii, colours, hardware flush). **Step 3:** fix geometry or lighting until the checklist passes. **Step 4:** commit `feat(cad-v2): viewer and drop-1 renders`.

### Task 12: Order list, spec sync, tag

**Files:** `docs/v2-order-list.md`, `hardware/bom_v2.csv` (generated, then priced), `docs/superpowers/specs/2026-09-29-rover-v2-design.md` (sync).

- [ ] **Step 1:** Search Indian listings (Robu, Robokits, Amazon.in) for: 2020 T-slot 1 m, spring T-nut M5, inside corner bracket 2020, 608 bearing, helical coupler 6→8 mm, M8 × 75 hex bolt and nyloc nuts, T8 lead screw 2 mm lead with brass flange nut; record price and basis in the BOM. **Step 2:** write `docs/v2-order-list.md`: purchased parts grouped for ordering, extrusion cut list (A = 380 + 380 + 232; B = 260 + 260 + 300), spare advice, cheaper substitutes. **Step 3:** sync the spec (M8 × 75, wheel cap, spacers, flexible helical coupler) and commit. **Step 4:** run `python tasks.py all`, then `git tag v2-drop1`.

---

## Self-review

- **Spec coverage:** A1 (Task 4, 7), A2 (Task 3, 10), A3/A4 (Task 3, 7), A5 (design rules in Tasks 5–7), A6/A7 reported (Task 4, 9; enforced from drop 2), A8–A10 arrive with later modules (drop 2/3), A12 (Task 11); §11 drop-1 contents: tooling (1–4, 9–11), chassis (6), drive modules and wheels (7), fit-test kit (8), order list (12).
- **Placeholders:** none; dimensions are in tables; tests are shown.
- **Type consistency:** `Item`, `Assembly.add`, `printed_item`, `to_bed`, `check_oriented`, `find_collisions`, `mass_properties`, `Y_STACK` used identically across tasks.

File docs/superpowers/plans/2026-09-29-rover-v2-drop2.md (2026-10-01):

# Rover v2 — Drop 2 (excavator: drum, arms, lift) Implementation Plan

> **For agentic workers:** Use superpowers:executing-plans (inline). Steps use checkbox (`- [ ]`) syntax.

**Goal:** Add the drum excavator and lift to the rover model, at five arm poses, passing collision, print, balance and load-path checks.

**Architecture:** As drop 1 (`Item`/`Assembly`, `checks/`, `export.py`). New modules build items for a given arm pose; kinematics places arms, drum, crossbar, lever, link and carriage from the pose angle.

**Tech Stack:** unchanged. **Spec:** `docs/superpowers/specs/2026-09-29-rover-v2-design.md` §7.3, §6, §9 (drop-1 plan is `2026-09-29-rover-v2-drop1.md`).

## Global Constraints

Same as drop 1 (bed 210 × 210 × 240, 180 g cap, overhang rule, collision ≤ 1 mm³, no drilling, M4 + nut traps, colours), plus:
- **Design changes decided while modelling (the spec is synced in Task 6):** arm pivot at x = 159, **z = 145** on brackets standing on the rail tops (clears the front motor and cradle); **arm length 150**; poses **press −28°, dig −25°, level 0°, mid +20°, carry +35°**; a **centre spine** (2020 × 260) joins the rear and front cross members and carries the lift; drum end plates are **one identical part**; the link is **two plates** flanking the lever and carriage ear; arms at |y| 106..118.
- Poses used by all checks: `POSES = (-28, -25, 0, 20, 35)`.

## File Structure (cad-v2/)

| File | Responsibility |
|---|---|
| `params.py` (modify) | pivot, arm, drum, lift constants, `POSES` |
| `modules/chassis.py` (modify) | add `spine` and its four brackets |
| `modules/drum.py` | `ring(clock)`, `plate()`, `spacer_long()` |
| `modules/arms.py` | `arm_drive`, `arm_idler`, `pivot_bracket`, `clamp_block`, `lever`, `link` |
| `modules/lift.py` | `channel`, `bearing_block`, `carriage`, `cradle_base`, `cradle_cap` |
| `modules/excavator.py` | `build(asm, pose)`: places everything for one arm angle; `carriage_x(pose)` |
| `assemble.py` (modify) | `rover(pose)` adds excavator |
| `checks/runner.py`, `tasks.py` (modify) | run all poses; mass and balance limits on |
| `calcs.py` | closed-form load checks (A10) |
| `tests/test_drum.py` `test_arms.py` `test_lift.py` `test_excavator.py` `test_calcs.py` | tests |

---

### Task 1: Frame spine and constants

- [ ] **Step 1: Failing test** `tests/test_chassis.py` adds: `spine` present, x −175..+84, y ±10, z 116..136; 12 brackets; 5 extrusions totalling 1 539 mm (`380+380+260+260+259`); still no collisions.
- [ ] **Step 2:** run → FAIL. **Step 3:** in `params.py` add `SPINE_X=(-175.0, 84.0)`, `PIVOT_Z=145.0`, `ARM_LEN=150.0`, `POSES=(-28, -25, 0, 20, 35)`, `ARM_Y=(106.0, 118.0)`, `DRUM_LEN=200.0`, `DRUM_R=80.0`, `DRUM_TIP_R=90.0`; in `chassis.build` add the spine (`extrusion(259)` along +X at y = 0) and four `_bracket_set` joints (spine × rear/front cross members, both sides). **Step 4:** PASS; commit.

### Task 2: Drum (`modules/drum.py`)

**Interfaces — Produces:** `ring(clock_deg: float) -> Part` (axis +Z, z 0..48, teeth and scoops rotated by `clock_deg`, four fixed lugs at 9.5° + 90°k with Ø4.4 axial holes at r = 84, 2 mm spigot on the z = 48 face and matching groove on z = 0); `plate() -> Part` (axis +Z: disc r 80, z 0..4, inner boss r 15 to z = 12 with hex pocket 13.4 AF × 5.5 from z = 12, Ø8.4 axial hole, spigot on z = 4 face, four lugs with holes); `spacer_long(length) -> Part`.
Shell 2.0 mm, tooth tips r 90, scoop opening 30°, baffle sweep 150° to core r 26, baffle 2 mm, tooth 4 mm (v1 values).

- [ ] **Step 1: Failing tests** `tests/test_drum.py`: ring valid single solid, height 48, max radius ≤ 90.01, mass 70..150 g, `check_oriented("ring", ring on z=0 face)` empty; ring A vs ring B (clock 0 vs 45) equal volume; 4 tie holes are Ø4.4 (an Ø4.4 pin at r = 84, angle 9.5° passes with < 1 mm³ overlap); plate valid, 4 lugs, hex pocket present (pin test), mass < 80 g; a stacked drum (plate, A, B, A, B, plate on z offsets 0,4,52,100,148,196) has no collisions and total length 200.
- [ ] **Step 2:** FAIL. **Step 3:** implement with 2D sketch booleans (shell annulus minus scoop sectors, baffle bands built from quads and joint circles, tooth band, lugs) then `extrude(48)`. **Step 4:** PASS; commit.

### Task 3: Arms, brackets, crossbar, lever, link (`modules/arms.py`)

**Interfaces — Produces:** arm-local frame = (along, up) from the pivot, thickness along Y. `arm_profile()` = hull of circles root (0,0,R17), crossbar ear (25,35,R16), tip (150,0,R24); `arm_drive()` (left, outer-face lightening pocket 8 mm, root 608 pocket Ø22.2 × 7.2 from the outer face with Ø17 floor hole, drum-end boss Ø36 with two 608 seats and web like the wheel housing, motor cradle roof/cap seats on the boss), `arm_idler()` (one 608 boss), `pivot_bracket()` (wall x ±30, y 118.8..124.8, z 136..165, top arc R 28 about the pivot; ears x ±12..30, y 118.8..150, z 136..141 with counterbored M5 holes at (±20, 140); Ø8.4 pivot hole and Ø11 × 0.8 boss), `clamp_block()` (wraps 2020, 2 M4 pinch bolts, 2 M4 mounting holes), `lever()`, `link()` (4 × 12 × 100, Ø5.4 holes).

- [ ] **Step 1: Failing tests** `tests/test_arms.py`: arms valid, plate thickness 12, bbox length ≈ 150 + R24 + R17, mass < 90 g each and pass `check_oriented`; bracket pass `check_oriented`; bracket wall pivot hole takes an M8 pin; lever pin at arm-local (−10, 80) within 0.01; link centre distance 100.
- [ ] **Step 2:** FAIL. **Step 3:** implement. **Step 4:** PASS; commit.

### Task 4: Lift (`modules/lift.py`)

**Interfaces — Produces:** screw axis y = 0, z = 155, x −20..130 (T8 × 2, 150 mm); `channel()` (x −25..133, base y ±17 z 136..141, walls y ±(13..17) to z = 166, four M5 feet), `bearing_block()` (14 × 26 × 30, 608 seat, identical ×2), `carriage()` (30 × 24 × 26 with nut bore and flange pocket, ear 8 mm wide to z = 184, pin hole Ø5.4 at z = 171), `cradle_base()` / `cradle_cap()` (Johnson 300 RPM motor on the spine, shaft along +X at z = 155), switches as 20 × 10 × 6 boxes at both ends of travel.

- [ ] **Step 1: Failing tests** `tests/test_lift.py`: parts valid and printable; screw passes through both bearings and the brass nut without overlap; carriage travel `[carriage_x(35), carriage_x(-28)]` lies inside the screw travel with ≥ 5 mm margin and has span ≥ 83 mm.
- [ ] **Step 2:** FAIL. **Step 3:** implement. **Step 4:** PASS; commit.

### Task 5: Excavator assembly and poses (`modules/excavator.py`)

**Interfaces — Consumes:** Tasks 2–4. **Produces:** `carriage_x(pose) -> float` (link 100 mm from lever pin to carriage pin, `p = pivot + R(pose)·(−10, 80)`, `x = p_x − sqrt(100² − (p_z − 171)²)`), `build(asm, pose)`, `moving` tags: arms, drum, drum motor, crossbar, lever, link, carriage → `"arm"`; wheels → `"spin"`.

- [ ] **Step 1: Failing tests** `tests/test_excavator.py`: for each pose in `POSES`, `find_collisions(rover(pose)) == []`; `sweep_problems` empty for moving vs static; at −25° the lowest tooth tip is within ±10 mm of −8 mm below ground and at +35° the tips are ≥ 100 mm above ground; stowed bbox at +35° ≤ 1500 × 750 × 750; overall width ≤ 560 mm.
- [ ] **Step 2:** FAIL. **Step 3:** implement; fix collisions by changing dimensions, never tests. **Step 4:** PASS; commit.

### Task 6: Balance, calcs, spec sync, drop tag

- [ ] **Step 1: Failing test** `tests/test_calcs.py`: each safety factor in `calcs.run()` ≥ 2; balance test in `tests/test_massprops_rover.py`: front share with 2 100 g sand at the drum centre at pose +35° ≤ 0.75 and empty mass ≤ 8 000 g.
- [ ] **Step 2:** FAIL. **Step 3:** implement `calcs.py` (wheel housing bending, axle, pivot bracket, arm root, lift link, tie rods, lead-screw lead angle vs friction 0.10) with printed inputs; turn on `MASS_LIMIT_G = 8000` and `FRONT_SHARE_LIMIT = 0.75` in `checks/runner.py`; update `tasks.py check` to loop `POSES`. **Step 4:** PASS. **Step 5:** update the spec (pivot z, arm length, poses, spine, plates, link, widths), commit and `git tag v2-drop2`.

---

## Self-review

- **Spec coverage:** §7.3 drum, arms, lift, crossbar, lever, link (Tasks 2–5); A1 five poses (Task 5), A7 balance and A10 calcs (Task 6). Trays, tower, body: drop 3.
- **Placeholders:** none; dimensions are in the interface blocks or spec §6/§7.3.
- **Type consistency:** `carriage_x(pose)`, `build(asm, pose)`, `POSES`, `ARM_LEN`, `PIVOT_Z` used identically across tasks.

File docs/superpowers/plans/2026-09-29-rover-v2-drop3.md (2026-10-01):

# Rover v2 — Drop 3 (electronics, tower, body, checks, documents) Implementation Plan

> **For agentic workers:** Use superpowers:executing-plans (inline). Steps use checkbox syntax.

**Goal:** Finish the machine (electronics tray, battery, sensor tower, hood, covers, handle, arrows, ToF noses), enforce the rules, balance and mass checks, lighten to the limit, and deliver renders, viewer, build guide, BOM, order list and change log.

**Architecture:** As drops 1–2. New modules build items into the same `Assembly`; `checks/rules.py` adds A8/A9; `checks/runner.py` turns on the mass and balance limits.

**Spec:** `docs/superpowers/specs/2026-09-29-rover-v2-design.md` §7.4–7.6, §8, §9, §11. Drop plans: `…-drop1.md`, `…-drop2.md`.

## Global Constraints
Same as drops 1–2 (bed 210 × 210 × 240, 180 g cap, overhang rule with bridges ≤ 8 mm, collisions ≤ 1 mm³, no drilling or inserts, colours by function, nothing pushed or published without the user's OK), plus:
- **Decided while modelling:** the tray halves are 3 mm plates with hanging ribs resting on the rails; the tie plate lies on top of both halves behind the lift motor; the hood is three panels printed upside down (1.6 mm walls); the tower is stacked collars that slide onto a 2020 post (each clamped by two M5 screws); arrows are three separate 0.8 mm plates taped on (a recess in a roof cannot print without bridging); ToF sensors sit on noses that bolt to the pivot-bracket walls; camera view rule: at pan 0° only the excavator may appear in the cone, at pan 180° nothing may.
- Mass: hard limit 8.0 kg empty, goal 7.5 kg; loaded front-axle share ≤ 75 %.

## Tasks
1. **Electronics parts and tray** (`lib/cots.py`, `modules/electronics.py`): boards as boxes from listings (Pi 5 85×56×17 with cooler, ESP32 51×28×12, BTS7960 ×4 50×50×16, buck 45×21×14, relay 30×28×28, fuse holders, battery pack 70×60×40, MPU6050); `tray_left`, `tray_right`, `tray_tie`, `batt_cradle`. Test: no collisions, tray parts pass `check_oriented`, boards sit on standoffs, gap ≥ 1 mm to the lift motor and cradle.
2. **Tower** (`modules/tower.py`): 300 mm post, `tower_base`, `tower_sleeve` ×2, `tower_estop`, `tower_pzem`, `tower_head` with SG90 and webcam, rear ToF. Test: parts printable, collar clamps take the post, E-stop head Ø60 at a side shelf, PZEM window faces −x.
3. **Body** (`modules/body.py`): `hood_left/right/spine`, `body_side_cover` ×2, `body_handle`, `body_arrow` ×3, `tof_nose` ×2. Test: hood panels ≤ 200 mm, no collisions at any pose, handle clears the link.
4. **Rules and balance** (`checks/rules.py`, `checks/runner.py`): A8 stowed size at pose 35, E-stop ≥ 40 mm with clear approach, PZEM display normal within ±30° of rearward and centre ≥ 250 mm high, three arrow plates on upward faces; A9 sensor cones; A6 mass ≤ 8 000 g, A7 loaded front share ≤ 75 %.
5. **Lightweighting pass** until the mass check passes: drum plates and rings, drive mounts, wheels, arm boss, hood walls.
6. **Documents and finish:** viewer and final renders (six fixed views, dig pose, exploded), `docs/v2-build-guide.md`, `hardware/bom_v2.csv`, `docs/v2-order-list.md`, `docs/v2-changelog.md`, `CONTEXT.md` update, spec sync, `git tag v2-drop3`.

## Self-review
Spec coverage: §7.4 tray/battery (T1), §7.5 tower (T2), §7.6 body (T3), A6–A9 (T4–5), §11 drop-3 documents (T6). No placeholders; dimensions are set in the modules and tests.

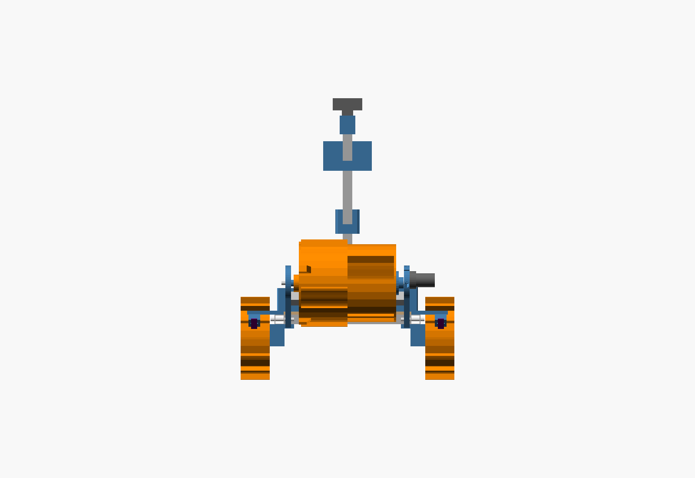
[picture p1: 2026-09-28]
docs/img/front.png

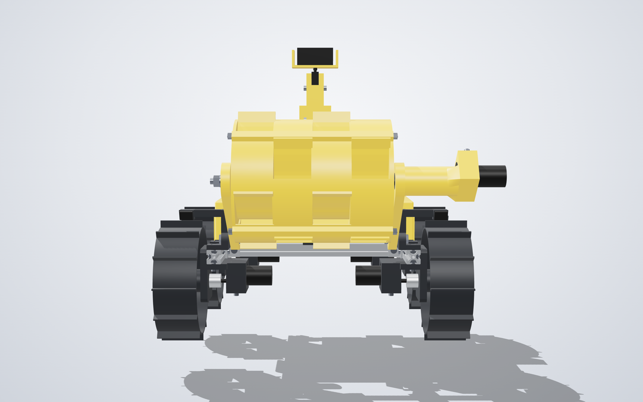
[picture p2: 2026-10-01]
docs/img/v2/front.png

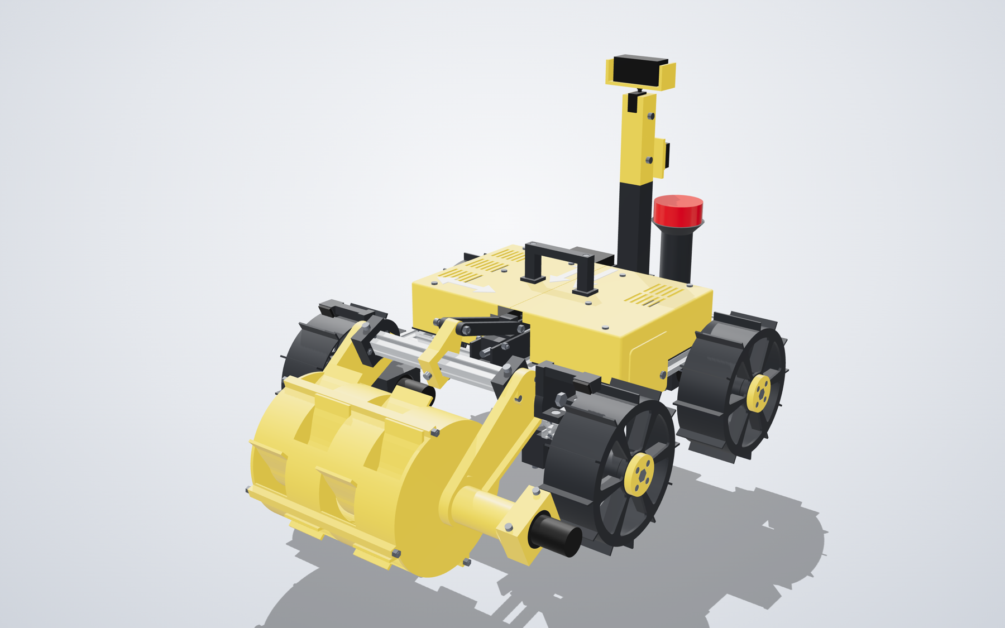
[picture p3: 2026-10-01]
docs/img/v2/dig_iso.png

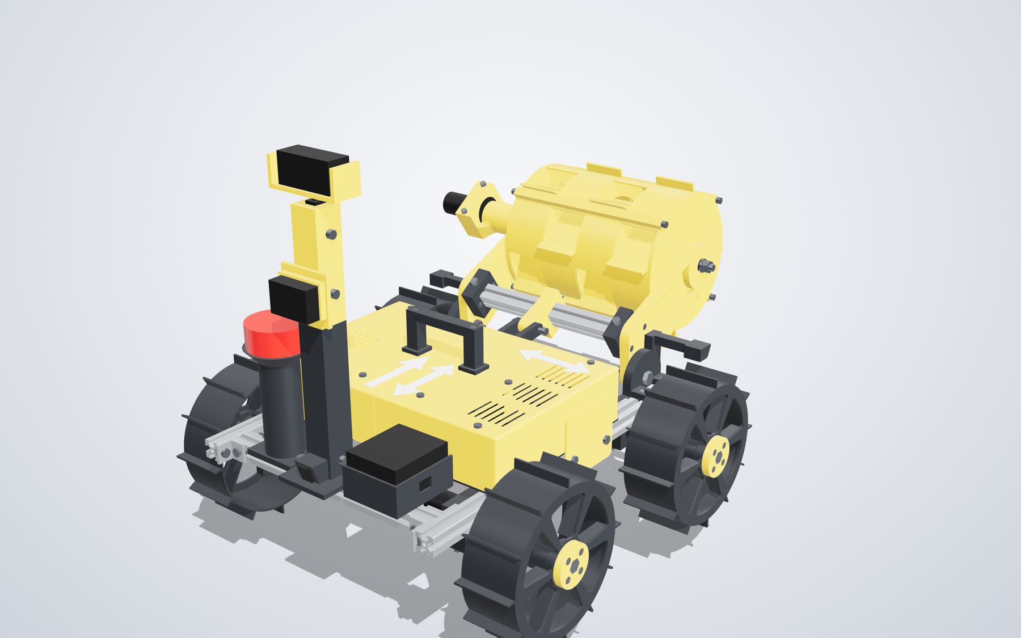
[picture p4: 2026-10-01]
docs/img/v2/rear_right.png

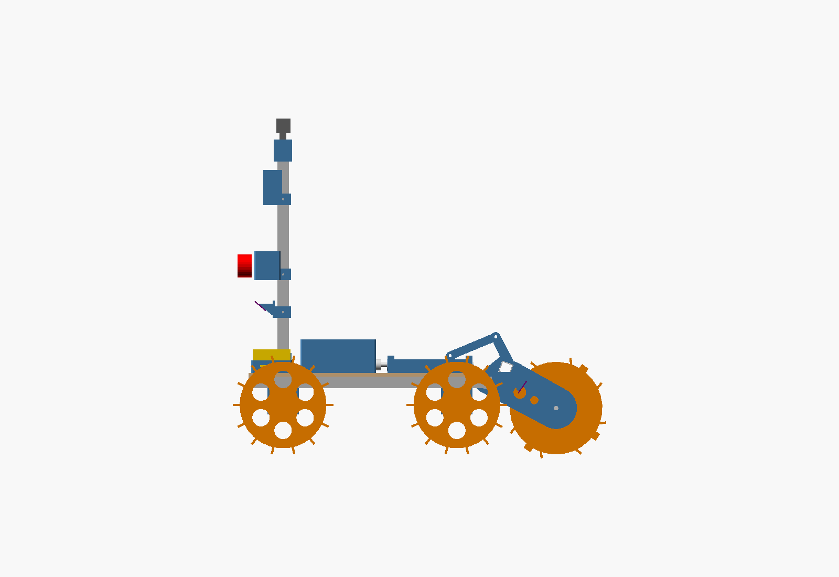
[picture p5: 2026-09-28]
docs/img/side_dig.png

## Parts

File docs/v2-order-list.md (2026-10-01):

# Rover v2: order list

Generated by `python tasks.py docs` from the model (`hardware/bom_v2.csv` has the same lines). Prices are INR including GST. **listed** = seen in an Indian store listing on 2026-09-29 (or v1's listing of 2026-09-28); **estimate** = a typical price, check before paying; **have** = the team owns it. Unchanged items keep v1's price so the two budgets compare.

**Total INR 23,329** with filament, wiring, practice sand and spares (cap INR 25,000; v1 INR 22,120). Not included: Raspberry Pi 5 (the team has it), the dual-band router (borrow), laptops, the printer, travel.

Order by about 5 October 2026 so parts arrive before the working-rover video window (10 October to 10 November).

## Frame: INR 2,168

| Item | Qty | Unit INR | Total INR | Basis | Where / note |
| :--- | ---: | ---: | ---: | :--- | :--- |
| 2020 T-slot, 1 m lengths | 3 | 420 | 1,260 | listed | Fastdep 420 incl. GST (heavy); Robu EasyMech 1 m; ~398 from. 2020 T-slot B-type slot 6, 1 m lengths, cut with a hacksaw (+-1 mm is fine) or by the vendor; one bar each: 402+402; 260+260+259; 240+212 |
| corner bracket 2020 | 12 | 25 | 300 | listed | 3DPrintronics 32; IndiaMART 19 per piece. 2020 inside corner bracket |
| T-nut M5 spring | 76 | 8 | 608 | estimate | Amazon.in kits / Mech Shop. M5 drop-in spring T-nut for a 2020 slot 6 (SuperbTech sliding nuts: 10 for 145) |

## Motors and motion: INR 3,766

| Item | Qty | Unit INR | Total INR | Basis | Where / note |
| :--- | ---: | ---: | ---: | :--- | :--- |
| motor_johnson_30rpm | 5 | 412 | 2,060 | listed | Robokits RKI-1156 (Grade A), 2026-09-29. Johnson 12 V 30 RPM side-shaft, 32 kg.cm (4 drive + 1 drum); measure one before printing the cradles |
| motor_johnson_300rpm | 1 | 477 | 477 | listed | Robokits RKI-1144 (Grade A), 2026-09-29. Johnson 12 V 300 RPM for the lift screw |
| bearing_608 | 15 | 35 | 525 | estimate | local / Robu. 608-2RS |
| coupler_6_8 | 6 | 100 | 600 | estimate | RoboticsDNA ZRB-19x25 at 65 (out of stock 2026-09-29); Robu 100-150. aluminium helical coupler 6 to 8 mm, D19 x L25 |
| M8 threaded rod 150 mm | 1 | 40 | 40 | estimate | local hardware. lift screw: cut 150 mm from a 1 m zinc or stainless M8 rod (about 100 INR per metre) |
| M8 brass nut | 2 | 12 | 24 | estimate | local hardware. brass hex nut M8, two per carriage |
| M4 threaded rod 211 mm | 4 | 10 | 40 | estimate | local hardware. drum tie rods: buy one 1 m M4 rod (about 40 INR) and cut four 211 mm lengths with a hacksaw |

## Electronics and sensors: INR 10,150

| Item | Qty | Unit INR | Total INR | Basis | Where / note |
| :--- | ---: | ---: | ---: | :--- | :--- |
| bts7960 | 4 | 300 | 1,200 | listed | Robokits RKI-6606 at 256; others 329-353 (v1 price). 43 A H-bridge driver: left drive, right drive, drum, lift |
| relay | 1 | 250 | 250 | estimate | Amazon.in / local electrical shop. 12 V 40 A automotive relay with socket, fails open |
| buck | 1 | 250 | 250 | estimate | Amazon.in / Robu. 5 V 5 A step-down (LM2596/XL4015 class) for the Pi and sensors |
| fuse_holder | 2 | 100 | 200 | estimate | Amazon.in / local electrical shop. inline blade-fuse holder (main and branch) |
| pi5 | 1 | 0 | 0 | have | the team has it. Raspberry Pi 5 with active cooler (excluded from the total) |
| esp32 | 1 | 500 | 500 | estimate | Robu / Amazon.in (v1 price). ESP32 dev board: motor PWM, encoders, limit switches |
| mpu6050 | 1 | 200 | 200 | estimate | Robu / Amazon.in (v1 price). 6-axis IMU, no magnetometer |
| battery_3s2p | 1 | 2500 | 2,500 | estimate | BatteryWorks 3S2P 5200 mAh pack listed at 900; pack with 20 A BMS and charger (v1 price). 3S2P Li-ion pack, 11.1 V, at least 20 A BMS, plus 12.6 V charger |
| estop | 1 | 400 | 400 | estimate | Evelta XB2-BS542 at 198 (head size not in the listing: the genuine XB2-BS542 is 40 mm, check it); Probots ProMax metal at 899. 22 mm panel-mount, twist-release, red mushroom head of at least 40 mm (modelled with 60 mm); any listed head size complies |
| estop_body | 1 | 0 | 0 | have | with the E-stop. contact block of the panel-mount E-stop (priced with the head) |
| pzem051 | 1 | 2000 | 2,000 | estimate | Robu.in (price not visible on 2026-09-29; Alibaba $8.5 wholesale). PZEM-051 DC energy meter with 50 A shunt, wired between battery and E-stop (v1 price, probably lower) |
| servo_sg90 | 1 | 150 | 150 | estimate | Robu / Amazon.in (v1 price). camera pan servo |
| webcam | 1 | 1000 | 1,000 | estimate | Amazon.in (v1 price). USB webcam 720p, driving view and AprilTag detection |
| tof_vl53 | 3 | 500 | 1,500 | listed | Robokits 402; KTRON 570 (v1 price). VL53L1X ToF sensor: 2 front (wheel tracks) + 1 rear; Class 1 laser (allowed) |

## Fasteners (buy assortments; quantities are what the model uses): INR 645

| Item | Qty | Unit INR | Total INR | Basis | Where / note |
| :--- | ---: | ---: | ---: | :--- | :--- |
| M5x8 button | 42 | 3 | 126 | estimate | local / Amazon.in. ISO 7380 button head |
| M8x75 hex | 4 | 18 | 72 | estimate | local hardware. ISO 4017 hex bolt, partly threaded (wheel axles) |
| M8 nyloc | 8 | 6 | 48 | estimate | local hardware. nyloc nut |
| M8 washer | 10 | 2 | 20 | estimate | local hardware. M8 washer |
| M5x12 button | 8 | 3 | 24 | estimate | local / Amazon.in. ISO 7380 button head |
| M5x14 button | 8 | 3 | 24 | estimate | local / Amazon.in. ISO 7380 button head |
| M4x40 socket | 10 | 3 | 30 | estimate | local / Amazon.in. ISO 4762 socket head |
| M4 nut | 44 | 1 | 44 | estimate | local / Amazon.in. hex nut |
| M4x14 socket | 16 | 2.5 | 40 | estimate | local / Amazon.in. ISO 4762 socket head |
| M5x10 button | 6 | 3 | 18 | estimate | local / Amazon.in. ISO 7380 button head |
| M8x35 hex | 2 | 13 | 26 | estimate | local hardware. ISO 4017 hex bolt (arm pivots) |
| M4 nyloc | 10 | 2 | 20 | estimate | local / Amazon.in. nyloc nut |
| M4x30 socket | 4 | 3 | 12 | estimate | local / Amazon.in. ISO 4762 socket head |
| M4x25 socket | 4 | 3 | 12 | estimate | local / Amazon.in. ISO 4762 socket head |
| M5x16 socket | 6 | 3 | 18 | estimate | local / Amazon.in. ISO 4762 socket head (clamp screws) |
| M5x40 socket | 2 | 4 | 8 | estimate | local / Amazon.in. ISO 4762 socket head (link pins) |
| M5 nyloc | 2 | 2.5 | 5 | estimate | local / Amazon.in. nyloc nut |
| M8x70 hex | 1 | 16 | 16 | estimate | local hardware. ISO 4017 hex bolt (drum drive axle) |
| M8x40 hex | 1 | 13 | 13 | estimate | local hardware. ISO 4017 hex bolt (drum idler axle) |
| M4x8 socket | 2 | 2.5 | 5 | estimate | local / Amazon.in. ISO 4762 socket head |
| M5x10 socket | 6 | 3 | 18 | estimate | local / Amazon.in. ISO 4762 socket head (collar clamp screws) |
| M4x60 button | 8 | 4 | 32 | estimate | local / Amazon.in. ISO 7380 button head (hood screws) |
| M4x100 socket | 2 | 5 | 10 | estimate | local / Amazon.in. ISO 4762 socket head (handle through-bolts) |
| M5 washer | 4 | 1 | 4 | estimate | local hardware. M5 washer |

## Aluminium cut list

Buy three 1 m lengths of 2020 (slot 6, B-type) and cut them as below; +-1 mm is fine, nothing else is drilled or tapped. The plan leaves at least 10 mm spare per bar for the saw kerf (about 3 mm per cut).

- Bar 1: 402 (rail (x2)) + 402 (rail (x2)); 193 mm left
- Bar 2: 260 (cross member (x2)) + 260 (cross member (x2)) + 259 (spine); 215 mm left
- Bar 3: 240 (tower post) + 212 (arm crossbar); 545 mm left

Two more cuts, both with a hacksaw: the four 211 mm M4 tie rods for the drum come from one 1 m rod, and the 150 mm M8 lift screw comes from a 1 m rod (keep the rest as a spare).

## Extras that are not in the model

| Item | Qty | Unit INR | Total INR | Basis | Where / note |
| :--- | ---: | ---: | ---: | :--- | :--- |
| PETG filament, 1 kg spools | 3 | 1000 | 3,000 | estimate | Amazon.in / local. printed total 2.55 kg; PETG 1.75 mm, 1 kg spool; buy the printed total x 1.10 for brims, purge and one reprint |
| Wire, connectors, XT60, ferrules, heat-shrink, cable ties | 1 | 1000 | 1,000 | estimate | local electrical shop. the 250 g wiring allowance in the mass budget |
| Practice sand pit + printed AprilTags | 1 | 1000 | 1,000 | estimate | local. beach, volleyball or construction sand is fine; for the working-rover video |
| Lift limit switches: 2 micro switches with lever, wire | 1 | 100 | 100 | estimate | Robu / Amazon.in. not in the model; one at each end of the lift channel |
| Spares (motor, driver, fuses, cells) | 1 | 1500 | 1,500 | estimate | Robokits / Robu / local. same allowance as v1 |

## Where the money could move

- The budget is under the cap by INR 1,671. The PZEM-051 is booked at v1's INR 2,000 because Robu did not show a price; similar meters list far lower, so expect INR 500 to 1,000 back.
- E-stop: the model uses a 60 mm head; any twist-release red mushroom of at least 40 mm complies, so check the head size of whatever you order. A plastic 22 mm unit (Evelta XB2-BS542 at INR 198) would do if its head is 40 mm or more; a metal one (Probots ProMax, INR 899) is sturdier.
- Johnson motors: Robokits lists the 30 RPM Grade A at INR 412 and the 300 RPM at INR 477; buy one spare (already inside the INR 1,500 spares line).
- If the printer is slow, the cheapest way to save print time is `body_side_cover_l/r`, the three arrow plates and `tower_sleeve_*` (cosmetic, about 60 g together). Nothing else can go without a redesign.

## Measure-first items

Sizes of the BTS7960 module, relay, buck converter, fuse holders, PZEM-051, E-stop body, battery pack and webcam are datasheet or listing values (`cad-v2/lib/cots.py`). Board holders have slotted screw holes (+-3 mm) so a different size still fits; the battery cradle is the one part sized to the pack (`BATT` in `modules/electronics.py`). Measure each item when it arrives and change the number before printing that part. The Johnson motor's gearbox diameter (37 mm) and shaft offset (7.5 mm) decide the four `drv_cradle_*` and the arm/lift clamps: measure one motor first.

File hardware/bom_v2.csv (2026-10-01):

item | qty | unit_price_inr | total_inr | price_basis | source | purchase_status | used_in | notes
2020 T-slot, 1 m lengths | 3 | 420 | 1260 | listed | Fastdep 420 incl. GST (heavy); Robu EasyMech 1 m; ~398 from | to buy | chassis/excavator/tower | 2020 T-slot B-type slot 6, 1 m lengths, cut with a hacksaw (+-1 mm is fine) or by the vendor; one bar each: 402+402; 260+260+259; 240+212
corner bracket 2020 | 12 | 25 | 300 | listed | 3DPrintronics 32; IndiaMART 19 per piece | to buy | chassis | 2020 inside corner bracket
M5x8 button | 42 | 3 | 126 | estimate | local / Amazon.in | to buy | chassis/excavator/electronics/tower/body | ISO 7380 button head
T-nut M5 spring | 76 | 8 | 608 | estimate | Amazon.in kits / Mech Shop | to buy | chassis/drive/excavator/electronics/tower/body | M5 drop-in spring T-nut for a 2020 slot 6 (SuperbTech sliding nuts: 10 for 145)
motor_johnson_30rpm | 5 | 412 | 2060 | listed | Robokits RKI-1156 (Grade A), 2026-09-29 | to buy | drive/excavator | Johnson 12 V 30 RPM side-shaft, 32 kg.cm (4 drive + 1 drum); measure one before printing the cradles
bearing_608 | 15 | 35 | 525 | estimate | local / Robu | to buy | drive/excavator | 608-2RS
coupler_6_8 | 6 | 100 | 600 | estimate | RoboticsDNA ZRB-19x25 at 65 (out of stock 2026-09-29); Robu 100-150 | to buy | drive/excavator | aluminium helical coupler 6 to 8 mm, D19 x L25
M8x75 hex | 4 | 18 | 72 | estimate | local hardware | to buy | drive | ISO 4017 hex bolt, partly threaded (wheel axles)
M8 nyloc | 8 | 6 | 48 | estimate | local hardware | to buy | drive/excavator | nyloc nut
M8 washer | 10 | 2 | 20 | estimate | local hardware | to buy | drive/excavator | M8 washer
M5x12 button | 8 | 3 | 24 | estimate | local / Amazon.in | to buy | drive | ISO 7380 button head
M5x14 button | 8 | 3 | 24 | estimate | local / Amazon.in | to buy | drive | ISO 7380 button head
M4x40 socket | 10 | 3 | 30 | estimate | local / Amazon.in | to buy | drive/excavator | ISO 4762 socket head
M4 nut | 44 | 1 | 44 | estimate | local / Amazon.in | to buy | drive/excavator/electronics/body | hex nut
M4x14 socket | 16 | 2.5 | 40 | estimate | local / Amazon.in | to buy | drive | ISO 4762 socket head
M5x10 button | 6 | 3 | 18 | estimate | local / Amazon.in | to buy | excavator | ISO 7380 button head
M8x35 hex | 2 | 13 | 26 | estimate | local hardware | to buy | excavator | ISO 4017 hex bolt (arm pivots)
tof_vl53 | 3 | 500 | 1500 | listed | Robokits 402; KTRON 570 (v1 price) | to buy | excavator/tower | VL53L1X ToF sensor: 2 front (wheel tracks) + 1 rear; Class 1 laser (allowed)
M8 threaded rod 150 mm | 1 | 40 | 40 | estimate | local hardware | to buy | excavator | lift screw: cut 150 mm from a 1 m zinc or stainless M8 rod (about 100 INR per metre)
motor_johnson_300rpm | 1 | 477 | 477 | listed | Robokits RKI-1144 (Grade A), 2026-09-29 | to buy | excavator | Johnson 12 V 300 RPM for the lift screw
M4 nyloc | 10 | 2 | 20 | estimate | local / Amazon.in | to buy | excavator | nyloc nut
M4x30 socket | 4 | 3 | 12 | estimate | local / Amazon.in | to buy | excavator | ISO 4762 socket head
M4x25 socket | 4 | 3 | 12 | estimate | local / Amazon.in | to buy | excavator | ISO 4762 socket head
M5x16 socket | 6 | 3 | 18 | estimate | local / Amazon.in | to buy | excavator | ISO 4762 socket head (clamp screws)
M5x40 socket | 2 | 4 | 8 | estimate | local / Amazon.in | to buy | excavator | ISO 4762 socket head (link pins)
M5 nyloc | 2 | 2.5 | 5 | estimate | local / Amazon.in | to buy | excavator | nyloc nut
M8 brass nut | 2 | 12 | 24 | estimate | local hardware | to buy | excavator | brass hex nut M8, two per carriage
M4 threaded rod 211 mm | 4 | 10 | 40 | estimate | local hardware | to buy | excavator | drum tie rods: buy one 1 m M4 rod (about 40 INR) and cut four 211 mm lengths with a hacksaw
M8x70 hex | 1 | 16 | 16 | estimate | local hardware | to buy | excavator | ISO 4017 hex bolt (drum drive axle)
M8x40 hex | 1 | 13 | 13 | estimate | local hardware | to buy | excavator | ISO 4017 hex bolt (drum idler axle)
bts7960 | 4 | 300 | 1200 | listed | Robokits RKI-6606 at 256; others 329-353 (v1 price) | to buy | electronics | 43 A H-bridge driver: left drive, right drive, drum, lift
relay | 1 | 250 | 250 | estimate | Amazon.in / local electrical shop | to buy | electronics | 12 V 40 A automotive relay with socket, fails open
buck | 1 | 250 | 250 | estimate | Amazon.in / Robu | to buy | electronics | 5 V 5 A step-down (LM2596/XL4015 class) for the Pi and sensors
fuse_holder | 2 | 100 | 200 | estimate | Amazon.in / local electrical shop | to buy | electronics | inline blade-fuse holder (main and branch)
pi5 | 1 | 0 | 0 | have | the team has it | have | electronics | Raspberry Pi 5 with active cooler (excluded from the total)
esp32 | 1 | 500 | 500 | estimate | Robu / Amazon.in (v1 price) | to buy | electronics | ESP32 dev board: motor PWM, encoders, limit switches
mpu6050 | 1 | 200 | 200 | estimate | Robu / Amazon.in (v1 price) | to buy | electronics | 6-axis IMU, no magnetometer
battery_3s2p | 1 | 2500 | 2500 | estimate | BatteryWorks 3S2P 5200 mAh pack listed at 900; pack with 20 A BMS and charger (v1 price) | to buy | electronics | 3S2P Li-ion pack, 11.1 V, at least 20 A BMS, plus 12.6 V charger
M4x8 socket | 2 | 2.5 | 5 | estimate | local / Amazon.in | to buy | electronics | ISO 4762 socket head
estop | 1 | 400 | 400 | estimate | Evelta XB2-BS542 at 198 (head size not in the listing: the genuine XB2-BS542 is 40 mm, check it); Probots ProMax metal at 899 | to buy | tower | 22 mm panel-mount, twist-release, red mushroom head of at least 40 mm (modelled with 60 mm); any listed head size complies
estop_body | 1 | 0 | 0 | have | with the E-stop | have | tower | contact block of the panel-mount E-stop (priced with the head)
pzem051 | 1 | 2000 | 2000 | estimate | Robu.in (price not visible on 2026-09-29; Alibaba $8.5 wholesale) | to buy | tower | PZEM-051 DC energy meter with 50 A shunt, wired between battery and E-stop (v1 price, probably lower)
servo_sg90 | 1 | 150 | 150 | estimate | Robu / Amazon.in (v1 price) | to buy | tower | camera pan servo
webcam | 1 | 1000 | 1000 | estimate | Amazon.in (v1 price) | to buy | tower | USB webcam 720p, driving view and AprilTag detection
M5x10 socket | 6 | 3 | 18 | estimate | local / Amazon.in | to buy | tower | ISO 4762 socket head (collar clamp screws)
M4x60 button | 8 | 4 | 32 | estimate | local / Amazon.in | to buy | body | ISO 7380 button head (hood screws)
M4x100 socket | 2 | 5 | 10 | estimate | local / Amazon.in | to buy | body | ISO 4762 socket head (handle through-bolts)
M5 washer | 4 | 1 | 4 | estimate | local hardware | to buy | body | M5 washer
PETG filament, 1 kg spools | 3 | 1000 | 3000 | estimate | Amazon.in / local | to buy | all printed parts | printed total 2.55 kg; PETG 1.75 mm, 1 kg spool; buy the printed total x 1.10 for brims, purge and one reprint
Wire, connectors, XT60, ferrules, heat-shrink, cable ties | 1 | 1000 | 1000 | estimate | local electrical shop | to buy |  | the 250 g wiring allowance in the mass budget
Practice sand pit + printed AprilTags | 1 | 1000 | 1000 | estimate | local | to buy |  | beach, volleyball or construction sand is fine; for the working-rover video
Lift limit switches: 2 micro switches with lever, wire | 1 | 100 | 100 | estimate | Robu / Amazon.in | to buy |  | not in the model; one at each end of the lift channel
Spares (motor, driver, fuses, cells) | 1 | 1500 | 1500 | estimate | Robokits / Robu / local | to buy |  | same allowance as v1
TOTAL (excludes the Raspberry Pi 5, which the team owns, the dual-band router, laptops, printer and travel) |  |  | 23329

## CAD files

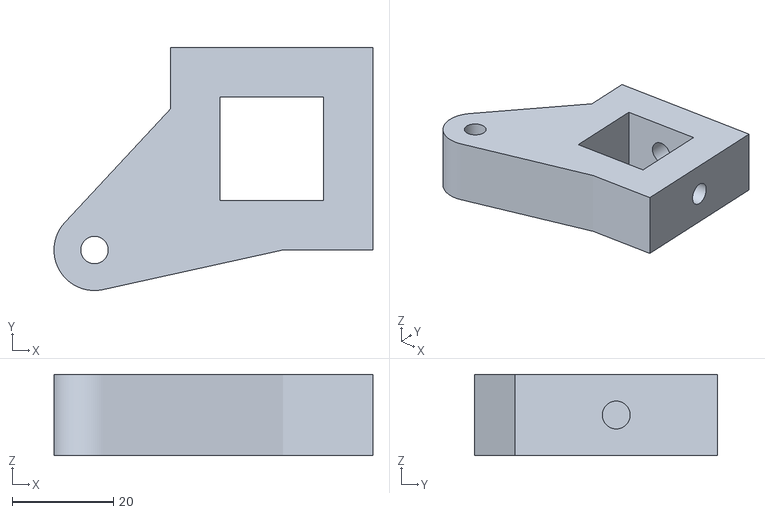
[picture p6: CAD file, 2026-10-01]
cad-v2/out/stl/lever.stl
63.0 x 48.0 x 16.0

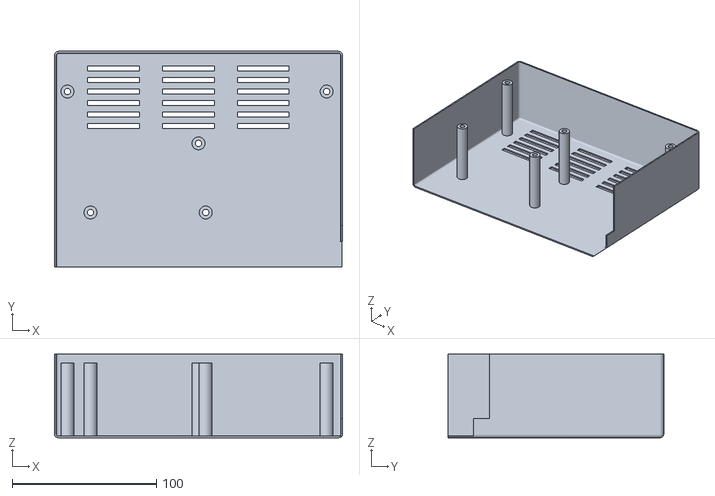
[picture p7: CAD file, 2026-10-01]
cad-v2/out/stl/hood_right.stl
200.0 x 149.7 x 58.0

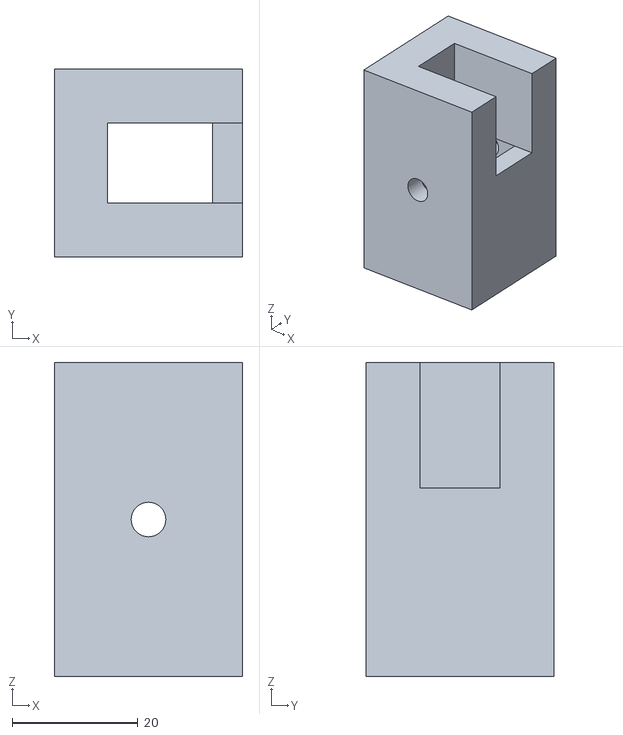
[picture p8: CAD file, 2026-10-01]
cad-v2/out/stl/tower_head.stl
30.0 x 30.0 x 50.0

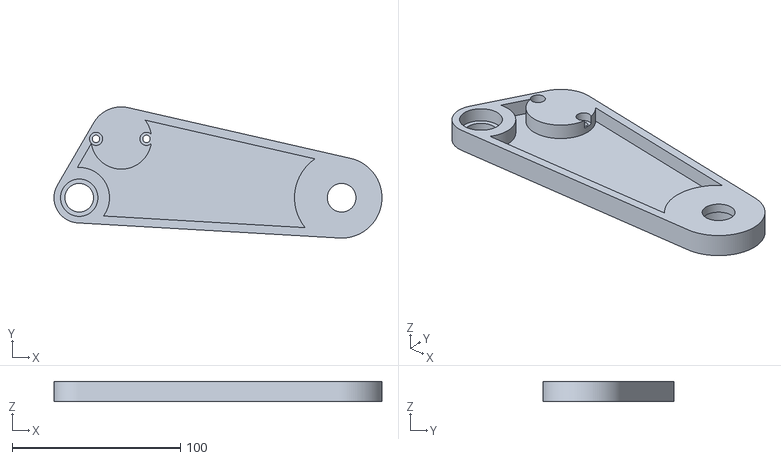
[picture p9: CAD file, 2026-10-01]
cad-v2/out/stl/arm_idler.stl
195.0 x 78.0 x 12.0

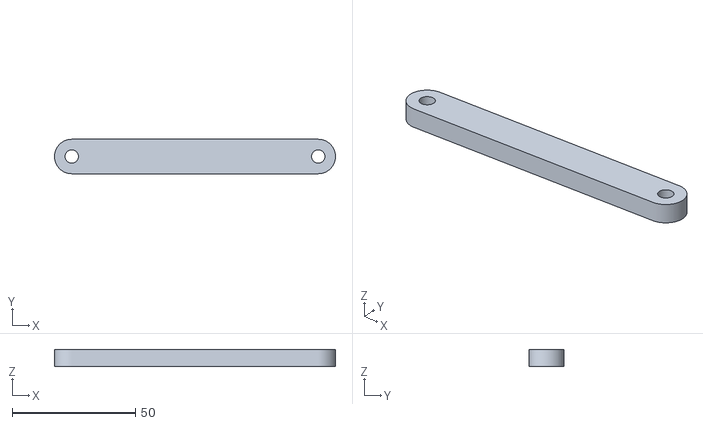
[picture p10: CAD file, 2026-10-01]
cad-v2/out/stl/lift_link.stl
114.0 x 14.0 x 7.00

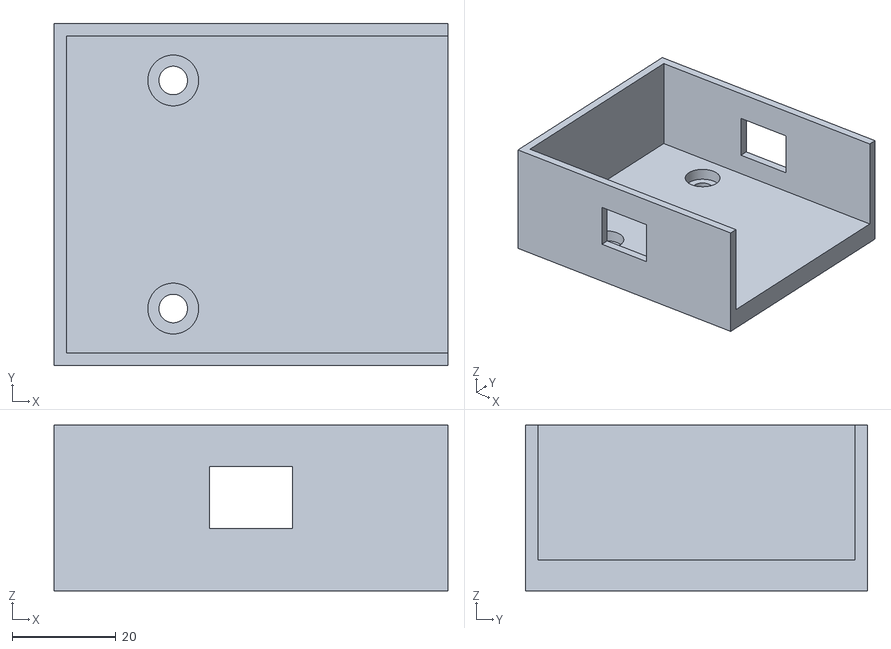
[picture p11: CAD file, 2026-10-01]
cad-v2/out/stl/batt_cradle.stl
76.0 x 66.0 x 32.0

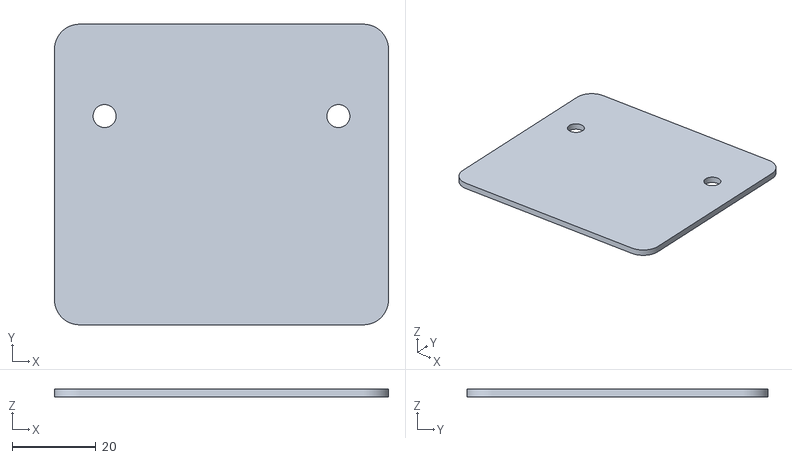
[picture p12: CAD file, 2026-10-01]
cad-v2/out/stl/body_side_cover_l.stl
80.0 x 72.0 x 2.00

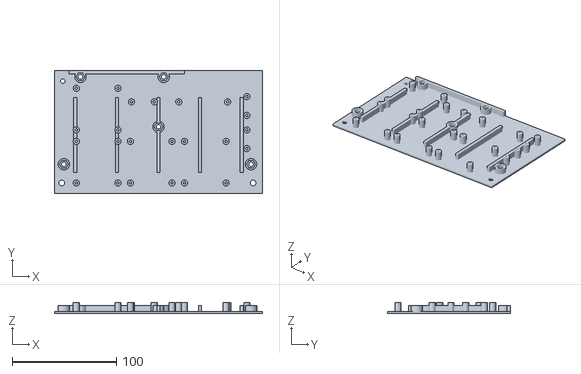
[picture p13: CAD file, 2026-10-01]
cad-v2/out/stl/tray_right.stl
200.0 x 118.0 x 11.0

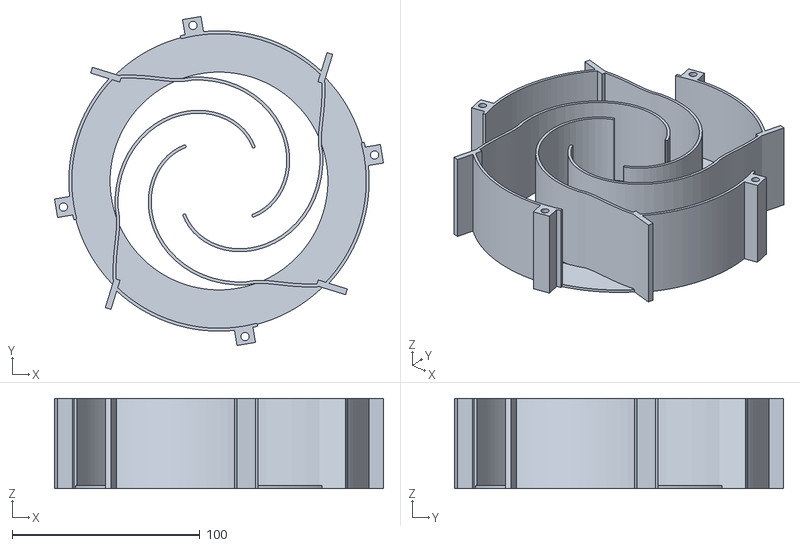
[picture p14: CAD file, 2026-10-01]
cad-v2/out/stl/drum_ring_b.stl
175.2 x 175.2 x 48.0

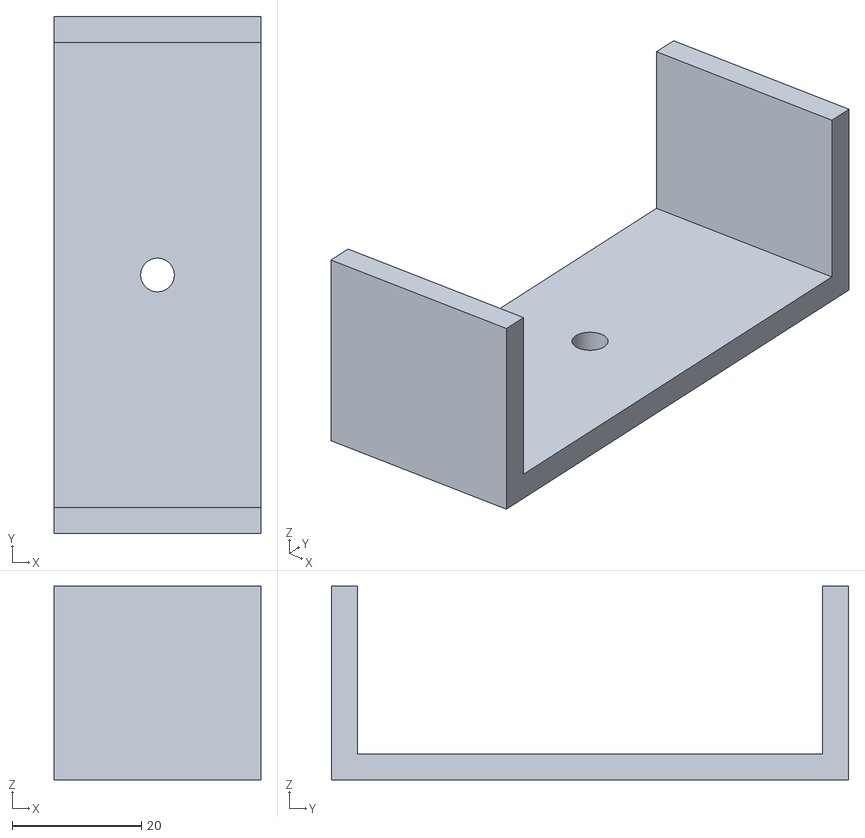
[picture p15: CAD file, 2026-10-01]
cad-v2/out/stl/camera_mount.stl
32.0 x 80.0 x 30.0

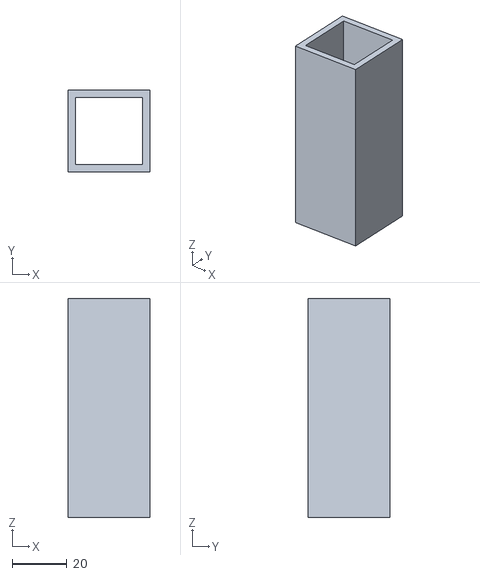
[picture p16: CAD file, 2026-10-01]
cad-v2/out/stl/tower_sleeve_80.stl
30.0 x 30.0 x 80.0

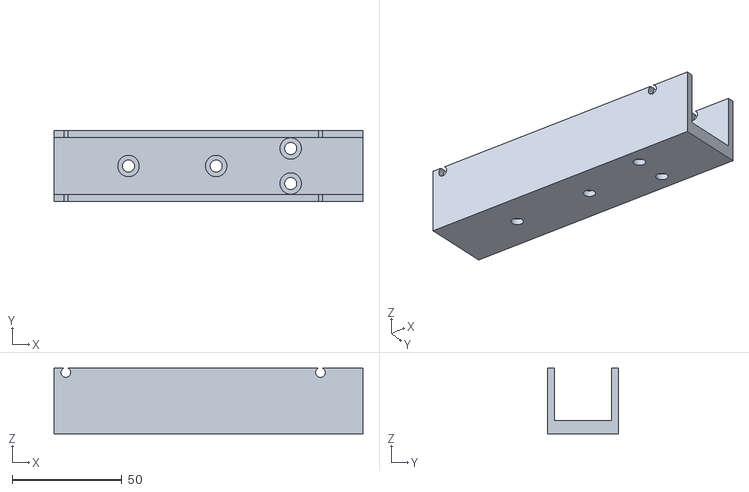
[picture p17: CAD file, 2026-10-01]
cad-v2/out/stl/lift_channel.stl
141.0 x 32.4 x 30.0

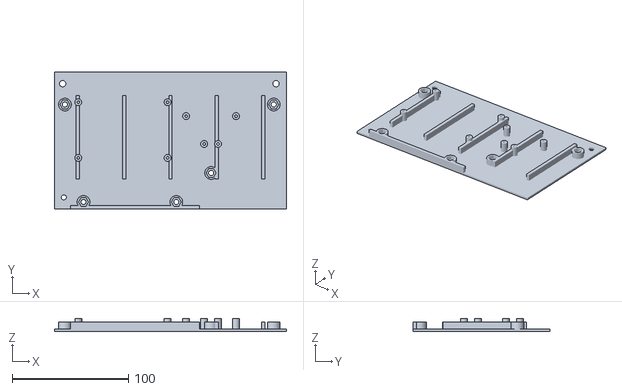
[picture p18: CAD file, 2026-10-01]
cad-v2/out/stl/tray_left.stl
200.0 x 118.0 x 11.0

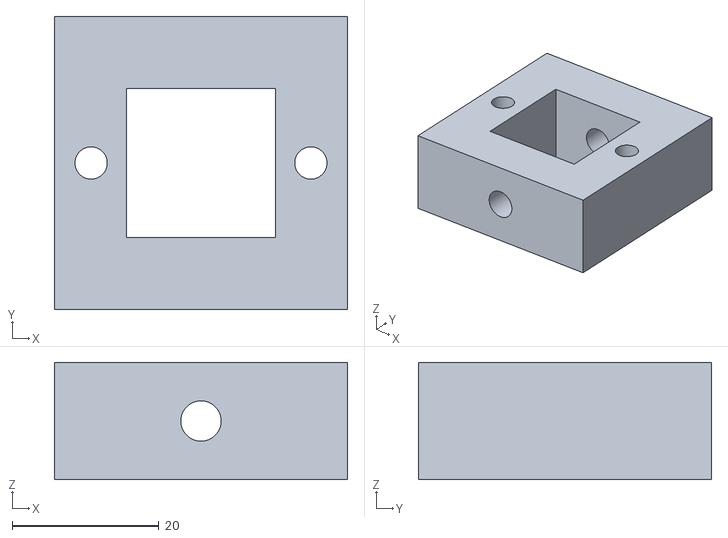
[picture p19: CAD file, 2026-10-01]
cad-v2/out/stl/clamp_block.stl
40.0 x 40.0 x 16.0

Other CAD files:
cad-v2/out/stl/drum_ring_a.stl
cad-v2/out/stl/hood_left.stl
cad-v2/out/stl/body_arrow.stl
cad-v2/out/stl/pivot_bracket_r.stl
cad/params.scad
legacy-v1-v2/cad/params.scad
cad/actuator.scad
cad/arm.scad
cad-v2/out/stl/arm_drive.stl
cad-v2/out/stl/arm_motor_cap.stl
cad-v2/out/stl/axle_spacer_62.stl
cad-v2/out/stl/axle_spacer_drum_mid.stl
cad-v2/out/stl/axle_spacer_end.stl
cad-v2/out/stl/axle_spacer_mid.stl
cad-v2/out/stl/body_arrow_double.stl
cad-v2/out/stl/body_handle.stl
cad-v2/out/stl/body_side_cover_r.stl
cad-v2/out/stl/drum_plate.stl
cad-v2/out/stl/drv_cradle_cap.stl
cad-v2/out/stl/drv_cradle_roof.stl
cad-v2/out/stl/drv_mount.stl
cad-v2/out/stl/estop_pedestal.stl
cad-v2/out/stl/fit_test_kit.stl
cad-v2/out/stl/lift_bearing_block.stl
cad-v2/out/stl/lift_carriage.stl
cad-v2/out/stl/lift_cradle_base.stl
cad-v2/out/stl/lift_cradle_cap.stl
cad-v2/out/stl/pivot_bracket_l.stl
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

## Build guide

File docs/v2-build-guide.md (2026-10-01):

# Rover v2: design and build guide

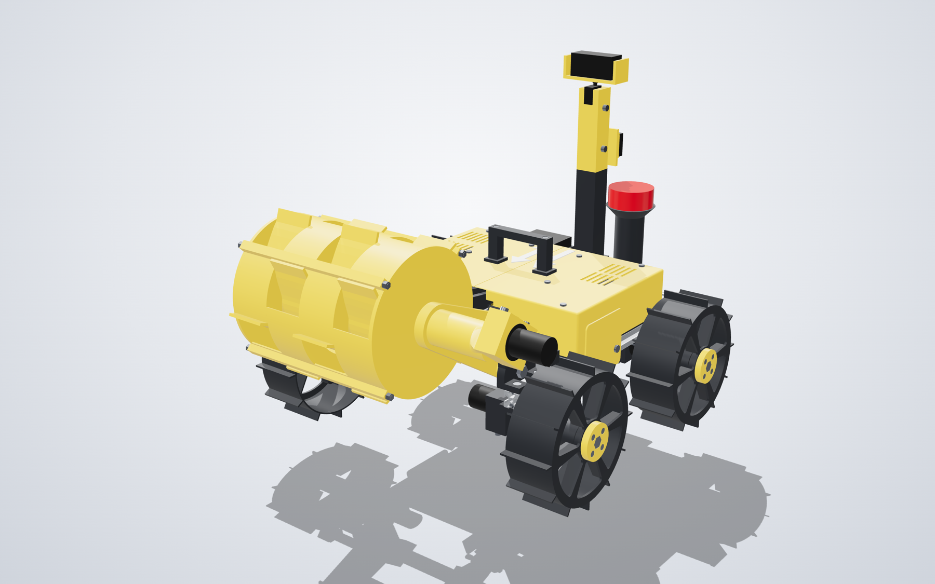
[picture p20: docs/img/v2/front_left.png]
Rover v2 at the carry pose


v2 keeps v1's idea (a light four-wheel skid-steer rover with a rotating bucket drum on a lift arm) and re-engineers everything
around it so a student team can build it with a 3D printer, hand tools and **no drilling, no tapping and no heat-set inserts**.
The whole rover is a parametric CAD model (`cad-v2/`, Python on the OpenCascade kernel, the same one FreeCAD uses). Every number
in this guide is generated from that model, and every claim is backed by a script that fails if it stops being true.

## 1. The numbers

<!-- BEGIN:numbers -->
| What | Value |
| :--- | :--- |
| Stowed size (carry pose) | 601 x 478 x 445 mm (limit 1500 x 750 x 750) |
| Wheelbase, track | 260 mm, 380 mm between wheel centres |
| Empty mass | 7.94 kg = 7.69 kg modelled + 250 g wiring allowance (limit 8.0 kg, goal 7.5 kg) |
| Mass with a full drum | 10.04 kg (2.1 kg of sand) |
| Front-axle share | 53 % empty, 74 % with a full drum at the carry pose (limit 75 %; v1: 80 %) |
| Centre of gravity, empty | x = 29, y = 7, z = 157 mm (x from the frame centre, forward positive) |
| Arm range | press -28 deg (teeth 10 mm below grade), dig -25 deg (4 mm below), level 0, mid +20, carry +35 deg (teeth 147 mm up) |
| Lift | M8 x 1.25 rod with two brass nuts, stroke 59 mm, self-locking |
| Printed parts | 43 part types, 2.55 kg of PETG (v1 rule: volume x 1.27 x 0.75), largest 137 g, no supports |
| Purchased | 48 SKUs, 352 pieces; total budget INR 23,329 with filament (cap 25,000; v1 22,120) |
<!-- END:numbers -->

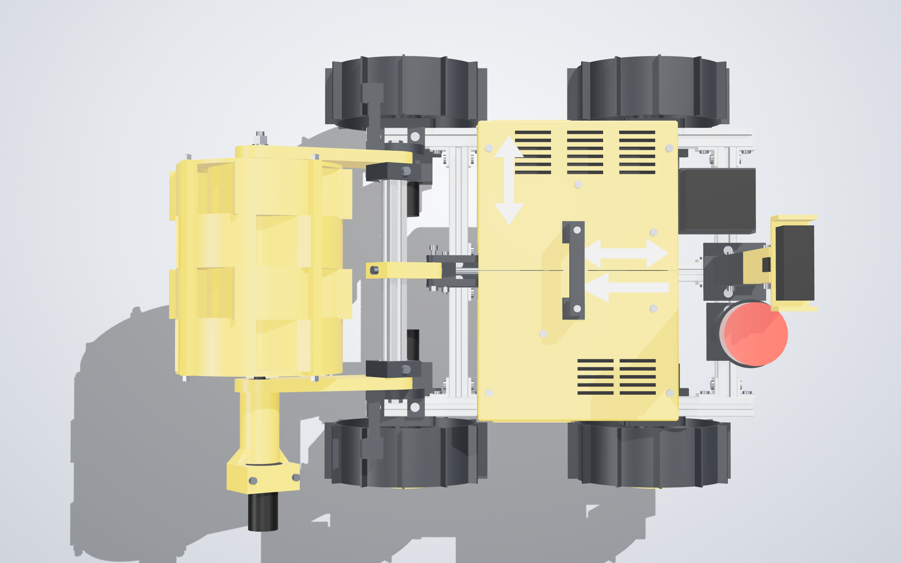
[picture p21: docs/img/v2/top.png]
Top view


## 2. What changed from v1

| v1 weak spot (from its own guide) | v2 |
|---|---|
| Wheels cantilevered on the gearbox shafts | Each wheel turns on two 608 bearings in a printed housing that bolts to the rail. The motor drives an M8 axle bolt through a helical coupler, so the gearbox carries torque only. |
| 80 % of the loaded weight on the front axle | 74 % with a full drum (2.1 kg of sand at the carry pose). The wheelbase is 260 mm and the electronics sit behind the axle centre. |
| Motor dimensions unmeasured, everything printed to guesses | A one-hour fit-test kit calibrates three tolerances first; every motor clamp is two pieces with slotted bolts; the measure-first list (section 9) says which parts depend on which measurement. |
| A one-piece drum that prints for about 20 hours | Four identical-height rings (101 g each, about 4 h) and two identical end plates (65 g), held by four M4 tie rods. Rings alternate by 45 degrees so the teeth are staggered. |
| Mesh-only STEP files | Proper B-rep STEP (opens in FreeCAD with 0 invalid shapes) and watertight STLs, one per part type. |
| Plywood deck and aluminium tube, heat-set inserts | 2020 T-slot frame and drop-in T-nuts; screws go into M4 nuts held in printed hex traps. |
| Wiring and boards loose in a box | A removable two-piece tray with standoffs for every board, a battery cradle, and a hood that hides all of it. |
| No way to prove it fits | Exact-solid collision checks at five arm poses, a 2 mm clearance sweep for every moving part, a floating-hardware check, a print-without-supports check, and hand-calculated load paths (section 8). |

## 3. Before you print anything: the fit-test kit

Print `out/stl/fit_test_kit.stl` first (about an hour, 100 x 66 mm). Left to right in each row the clearance grows:

| Row | What it holds | Columns |
|---|---|---|
| Bearing seats | 608 bearing, 22 mm | seat diameter 22.0 / 22.1 / 22.2 mm |
| Nut traps | M4 nut and M8 nut | hex across-flats +0.2 / +0.4 / +0.6 mm |
| Holes | M4 and M5 bolts | diameter +0.2 / +0.4 / +0.6 mm |
| Motor slice | the Johnson gearbox, 37 mm | the saddle at the right-hand end |

Push a real 608, M4 nut, M8 nut, M4 and M5 bolts, and the motor gearbox into the columns. Pick the first column that goes in by hand without
force and does not rattle. Then set the numbers in `cad-v2/params.py` and regenerate:

```python
TOL_BEARING = 0.2   # bearing seat = 22.0 + this   (kit columns: 0.0 / 0.1 / 0.2)
TOL_TRAP = 0.4      # hex trap across-flats = nut + this   (0.2 / 0.4 / 0.6)
TOL_HOLE = 0.4      # bolt hole = bolt + this   (0.2 / 0.4 / 0.6)
```

```bash
cd cad-v2 && source .venv/bin/activate && python tasks.py all
```

Until you have done this, print nothing large. If the motor does not sit in the saddle, measure the gearbox (`JM_GEAR_D`, `JM_SHAFT_OFF` in `params.py`).

## 4. Print list

Settings that all parts assume: PETG, 0.4 mm nozzle, 0.2 mm layers, 4 walls, 25 % gyroid infill, **no supports**, 5 mm brim on the tall thin parts
(`tower_*`, `estop_pedestal`, `body_handle`). The thin-walled parts (hood, wheels, drum rings, plates) are almost all walls, so infill hardly matters
for them. Every STL is already turned into its print position. Masses use v1's rule (volume x 1.27 g/cm3 x 0.75); weigh one wheel after printing
and change `FILL` in `params.py` if it is far off, then regenerate.

<!-- BEGIN:print -->
**Drive modules**

| Part (STL name) | Qty | Size in print position, mm | g each | g total | Colour |
| :--- | ---: | :--- | ---: | ---: | :--- |
| `drv_mount` | 4 | 64 x 76 x 57 | 68 | 271 | graphite |
| `drv_cradle_roof` | 4 | 76 x 54 x 8 | 24 | 95 | graphite |
| `drv_cradle_cap` | 4 | 56 x 28 x 35 | 24 | 98 | graphite |
| `axle_spacer_mid` | 4 | 11 x 11 x 23 | 1 | 3 | graphite |
| `axle_spacer_end` | 9 | 11 x 11 x 2 | 0 | 1 | graphite |
| `wheel` | 4 | 174 x 174 x 60 | 111 | 444 | graphite |
| `wheel_cap` | 4 | 44 x 44 x 8 | 10 | 39 | yellow |

**Excavator: drum, arms, lift**

| Part (STL name) | Qty | Size in print position, mm | g each | g total | Colour |
| :--- | ---: | :--- | ---: | ---: | :--- |
| `pivot_bracket_l` | 1 | 62 x 56 x 68 | 36 | 36 | graphite |
| `pivot_bracket_r` | 1 | 62 x 56 x 68 | 36 | 36 | graphite |
| `lift_channel` | 1 | 141 x 32 x 30 | 45 | 45 | graphite |
| `lift_bearing_block` | 2 | 26 x 26 x 14 | 5 | 11 | graphite |
| `lift_cradle_base` | 1 | 29 x 62 x 27 | 29 | 29 | graphite |
| `lift_cradle_cap` | 1 | 29 x 62 x 22 | 21 | 21 | graphite |
| `arm_drive` | 1 | 199 x 78 x 106 | 137 | 137 | yellow |
| `arm_idler` | 1 | 195 x 78 x 12 | 73 | 73 | yellow |
| `arm_motor_cap` | 1 | 56 x 25 x 22 | 15 | 15 | yellow |
| `clamp_block` | 2 | 40 x 40 x 16 | 17 | 34 | graphite |
| `lever` | 1 | 63 x 48 x 16 | 26 | 26 | yellow |
| `lift_link` | 2 | 114 x 14 x 7 | 10 | 20 | graphite |
| `lift_carriage` | 1 | 24 x 24 x 43 | 15 | 15 | graphite |
| `drum_plate` | 2 | 175 x 175 x 12 | 65 | 130 | yellow |
| `drum_ring_a` | 2 | 181 x 181 x 48 | 101 | 203 | yellow |
| `drum_ring_b` | 2 | 175 x 175 x 48 | 101 | 203 | yellow |
| `axle_spacer_62` | 3 | 11 x 11 x 6 | 0 | 1 | graphite |
| `axle_spacer_drum_mid` | 1 | 11 x 11 x 19 | 1 | 1 | graphite |

**Electronics tray and battery**

| Part (STL name) | Qty | Size in print position, mm | g each | g total | Colour |
| :--- | ---: | :--- | ---: | ---: | :--- |
| `tray_left` | 1 | 200 x 118 x 11 | 55 | 55 | graphite |
| `tray_right` | 1 | 200 x 118 x 11 | 59 | 59 | graphite |
| `tray_tie` | 1 | 10 x 104 x 6 | 6 | 6 | graphite |
| `batt_cradle` | 1 | 76 x 66 x 32 | 40 | 40 | graphite |

**Sensor tower and E-stop**

| Part (STL name) | Qty | Size in print position, mm | g each | g total | Colour |
| :--- | ---: | :--- | ---: | ---: | :--- |
| `tower_base` | 1 | 64 x 60 x 35 | 39 | 39 | graphite |
| `tower_sleeve_80` | 1 | 30 x 30 x 80 | 23 | 23 | graphite |
| `tower_sleeve_40` | 1 | 30 x 30 x 40 | 12 | 12 | graphite |
| `tower_pzem` | 1 | 40 x 56 x 60 | 40 | 40 | yellow |
| `tower_head` | 1 | 30 x 30 x 50 | 25 | 25 | yellow |
| `estop_pedestal` | 1 | 66 x 66 x 115 | 54 | 54 | graphite |
| `camera_mount` | 1 | 32 x 80 x 30 | 16 | 16 | yellow |

**Body**

| Part (STL name) | Qty | Size in print position, mm | g each | g total | Colour |
| :--- | ---: | :--- | ---: | ---: | :--- |
| `hood_left` | 1 | 200 x 150 x 58 | 74 | 74 | yellow |
| `hood_right` | 1 | 200 x 150 x 58 | 73 | 73 | yellow |
| `body_side_cover_l` | 1 | 80 x 72 x 2 | 11 | 11 | yellow |
| `body_side_cover_r` | 1 | 80 x 72 x 2 | 11 | 11 | yellow |
| `body_handle` | 1 | 22 x 98 x 46 | 26 | 26 | graphite |
| `body_arrow` | 1 | 90 x 30 x 1 | 1 | 1 | white |
| `body_arrow_double` | 2 | 90 x 30 x 1 | 1 | 2 | white |

Total 2.55 kg of PETG in 43 part types (about 102 print hours at 25 g/h; the longest single print is 137 g, about 5 h). Every STL in `cad-v2/out/stl/` is already turned into its print position and sits on z = 0.
<!-- END:print -->

Print in this order so you can start assembling early: fit-test kit, drive module parts (mounts, cradles, wheels, caps), electronics tray, excavator, tower, body.
Colours follow function: yellow for the parts that work the ground (drum, arms, hood, tower head), graphite for structure and drive, white for the arrow plates.

## 5. Buy list

See [`v2-order-list.md`](v2-order-list.md) (generated from the model, priced, with the aluminium cut list) and [`../hardware/bom_v2.csv`](../hardware/bom_v2.csv).

## 6. Assembly

Suggested order: frame, four drive modules, electronics tray, excavator, tower, body. Two people can work in parallel (one on the drive modules and excavator, one on the electronics and tower). Use a drop of thread-locker on the M8 axle nuts only if you use plain nuts; the nylon-insert nuts in the list do not need it. Tighten M4 screws
into printed traps until snug, no further: PETG creeps under a hard-tightened screw.

Open `out/rover_v2_viewer.html` in a browser next to this guide. Hover any part to see its name, drag the *Explode* slider to see how it stacks up, and switch the
hood off to see the tray.

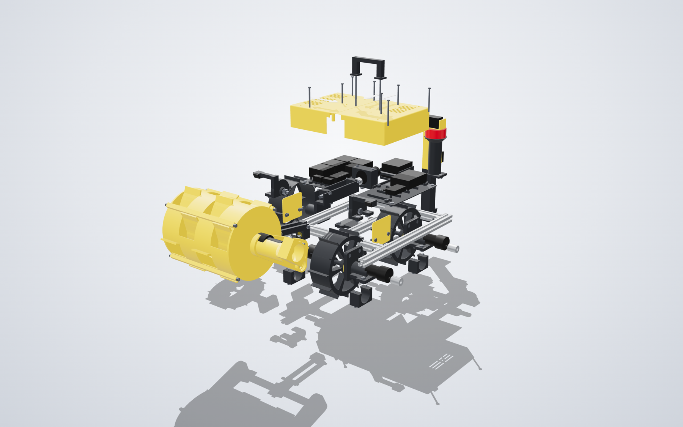
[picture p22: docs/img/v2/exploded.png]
Exploded view


### 6.1 Frame (no printed parts)

1. Cut the 2020 to the lengths in the order list: two rails 402 mm, two cross members 260 mm, the spine 259 mm, the arm crossbar 212 mm and the tower post 240 mm.
2. Lay the rails 260 mm apart (inside faces) and put a corner bracket at each inside corner of the two cross members: one on the front face and one on the back face
   at every end of both cross members (eight in all). The rear cross member sits at x = -185 mm, the front one at x = +94 mm. The rails stick out 17 mm behind the
   rear cross member; that stub holds the outer brackets.
3. Fit the spine between the cross members with four more brackets, two at each end.
4. Every bracket takes two M5 x 8 button screws into drop-in T-nuts. Check the frame is square (diagonals within 1 mm) before tightening.

### 6.2 Drive modules, four times

Each module is a motor, a coupler, a mount plate with a two-bearing housing, a two-piece motor clamp and a wheel. Front axle x = +150, rear axle x = -110.

1. **Mount plate** (`drv_mount`): two M5 x 12 screws with T-nuts into the rail's outer slot. The housing points outward.
2. **Bearings**: press one 608 into each end of the housing (the seats are open at both ends; the web in the middle stops them).
3. **Motor clamp**: `drv_cradle_roof` goes under the rail with two M5 x 14 screws into the rail's bottom slot (the holes are slotted 3 mm along the rail, so you can
   line the motor up). The roof carries two M4 nuts in hex traps.
4. **Axle**, from the outside in: `wheel_cap` with the M8 x 75 bolt head in its hex pocket, the wheel (four M4 x 14 screws join cap and wheel; the nuts are in the hub),
   spacer, bearing, the long spacer, bearing, spacer, washer, and the nyloc nut on the inside. Tighten until the wheel still spins freely with a finger.
5. **Motor**: slide the coupler over the bolt end, put the motor shaft into the other end, lay the motor gearbox in the roof's saddle, close it with `drv_cradle_cap`
   (two M4 x 40 from below into the roof's nuts) and tighten the coupler screws on the shaft flat.

### 6.3 Electronics tray

1. `tray_left` and `tray_right` rest on the rails either side of the spine; two M5 x 8 screws each go into T-nuts in the rails' top slots (at x = -118 and +66).
2. `tray_tie` joins the two halves behind the lift motor: two M4 x 8 from underneath into nuts in its underside.
3. Boards go on the standoffs (M2.5 self-tapping screws): four BTS7960 drivers, relay, 5 V buck and two fuse holders on the **right** half (the power bay, next to the battery);
   Raspberry Pi 5, ESP32 and MPU6050 on the **left** half (the compute bay).
4. `batt_cradle` bolts to the rear cross member (two M5 x 8). The battery sits in it with a 16 mm hook-and-loop strap through the two slots.
5. Wire before the hood goes on. Mandatory by the rules: the PZEM-051 sits between the battery and the E-stop, and one press of the E-stop cuts the battery from all controllers.
   Cable routes are not modelled, but the space is there: motor cables come up through the 22 mm gap between the spine / lift channel and the tray edges (y = 16 to 32 mm) and stay under the hood;
   the drum-motor cable follows the left arm to the pivot (leave a service loop there) and enters through the front port; the E-stop wires run down the pedestal bore.
   The PZEM's 50 A shunt is a separate bar: cable-tie it to a tray rib next to the fuse holders.

### 6.4 Excavator

1. **Pivot brackets**: each stands on a rail top with two M5 x 10 screws at x = 139 and 179. The front ToF sensor goes on its sloping pad (25 degrees below forward).
2. **Arms**: press a 608 into each arm's root, from the outer face. The arm goes on the bracket with an M8 x 35 bolt through the wall (head outside), a washer between wall and arm,
   the bearing, a washer and a nyloc nut. The arms swing freely with no side play.
3. **Drum**: end plate, ring A, ring B, ring A, ring B, second end plate (turn the second plate over about the axis: the four lug holes still line up). Four M4 rods
   211 mm long pass through the lugs; a nyloc nut on each end. Rings A and B are the same part turned 45 degrees in the print (`drum_ring_a`, `drum_ring_b`).
4. **Drum axle**: M8 x 70 on the drive side (head in the plate's hex pocket), M8 x 40 on the idler side, each through two 608 in the arm boss; spacers as in the model.
   The drum motor sits in `arm_drive` and `arm_motor_cap` (two M4 x 30) and drives the axle through a coupler.
5. **Crossbar and lever**: the 212 mm crossbar spans the arms. `clamp_block` (one per arm) is held on the arm by two M4 x 25 and pinches the crossbar with two M5 x 16.
   The `lever` is clamped to the middle of the crossbar the same way.
6. **Lift**: `lift_channel` stands on the spine and the front cross member (four M5 x 8). The two bearing blocks sit inside it, joined by the M8 rod with the coupler
   to the lift motor (`lift_cradle_base` and `lift_cradle_cap`, two M4 x 30, on the spine). The carriage holds two brass M8 nuts, one in each end.
   Two links (`lift_link`) connect the carriage to the lever with M5 x 35 pins and nyloc nuts.
7. Two micro limit switches are **not** in the model: put one at each end of the channel so the carriage trips them at x = 13 mm and x = 86 mm (the working range is 20 to 79.5 mm).

### 6.5 Sensor tower

1. `tower_base` bolts to the rear cross member (two M5 x 8). The rear ToF looks 20 degrees below horizontal from its wedge.
2. The 240 mm post stands in the base's socket. Every collar (`tower_base` socket, `tower_pzem`, `tower_head`) clamps with two M5 x 10 screws into T-nuts in the post's side slots.
   The two sleeves (`tower_sleeve_80`, `tower_sleeve_40`) just slide down over the post from the top.
3. The PZEM-051 sits on the rear plate of `tower_pzem`, display facing back, 321 mm above the ground.
4. The SG90 servo drops into the pocket in `tower_head`; `camera_mount` goes on its horn; the webcam sits on the platform, lens forward at pan 0.
5. `estop_pedestal` bolts to the rear cross member left of the tower (two M5 x 8). The E-stop clamps in its 22.4 mm hole and the contact block hangs in the bore.

### 6.6 Body

1. Lay `hood_left` and `hood_right` on the tray. Ten M4 screws (eight M4 x 60 button heads and two M4 x 100 through the handle) go down the posts into the nuts in the tray bosses.
   The two halves meet with a 0.6 mm reveal down the centre line.
2. The handle (`body_handle`) stands on the two inner posts at x = -20 mm; its two M4 x 100 bolts run right through it.
3. `body_side_cover_l` and `_r` go on the rails' outer faces between the wheels (two M5 x 8, washer and T-nut each).
4. Three arrow plates lie on the hood roof with double-sided tape: forward (single head, points +x), length (double head along x), width (double head along y).

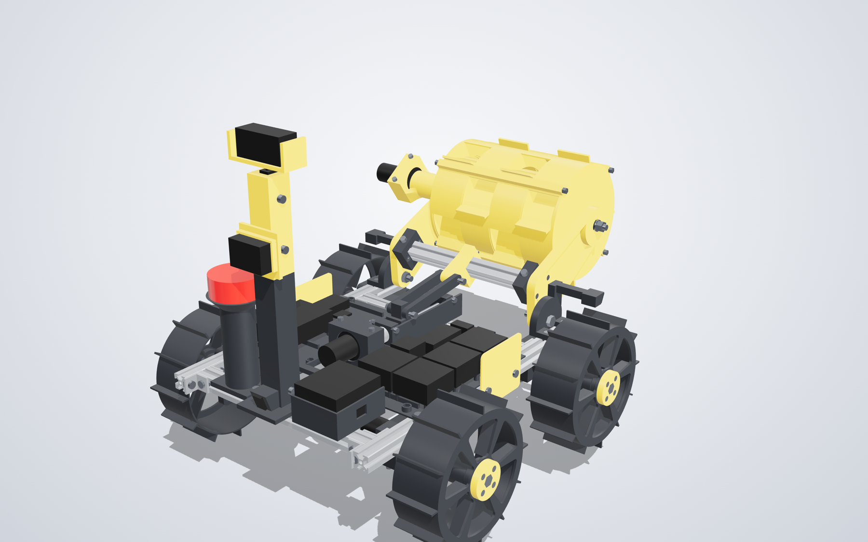
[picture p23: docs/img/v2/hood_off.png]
Hood off: the tray and the lift


## 7. Arm poses

The lift rod moves the carriage 60 mm; the links turn that into the arm angle. The table is from the model.

<!-- BEGIN:poses -->
| Arm angle | Name | Lowest tooth tip, mm above ground | Highest point of the drum, mm | Carriage on the rod, x mm |
| ---: | :--- | ---: | ---: | ---: |
| -28 deg | press | -10 | 160 | 79.5 |
| -25 deg | dig | -4 | 168 | 76.9 |
| +0 deg | level | +57 | 239 | 53.0 |
| +20 deg | mid | +117 | 285 | 33.1 |
| +35 deg | carry / dump | +147 | 327 | 20.0 |
<!-- END:poses -->

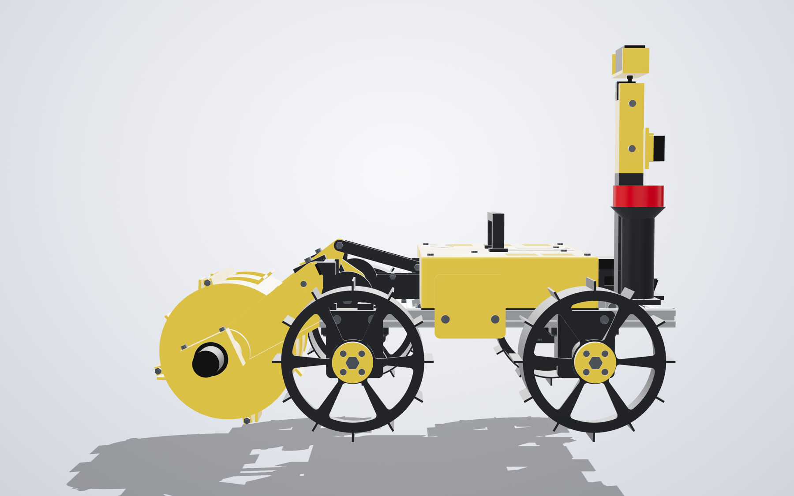
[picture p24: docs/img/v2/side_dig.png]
Dig pose


Digging is done by spinning the drum with the arm lowered to the dig or press pose while the rover creeps forward; the spiral baffles carry sand to the core.
Reverse the drum to dump. At the carry pose the teeth are about 147 mm above the ground and the rover is 601 x 478 x 445 mm.

## 8. Mass, balance and load paths

<!-- BEGIN:mass -->
| Module | Items | Printed g | Bought g | Total g |
| :--- | ---: | ---: | ---: | ---: |
| chassis | 65 | 0 | 1052 | 1052 |
| drive | 140 | 950 | 1654 | 2604 |
| excavator | 126 | 1036 | 1246 | 2283 |
| electronics | 32 | 160 | 636 | 796 |
| tower | 34 | 209 | 467 | 677 |
| body | 40 | 198 | 86 | 284 |
| **modelled total** | 437 | **2553** | **5142** | **7695** |
| wiring allowance (not modelled) |  |  |  | 250 |
| **empty** |  |  |  | **7945** |
<!-- END:mass -->

The wiring allowance (250 g) stands in for cables, connectors and ties, which are not modelled. Printed masses follow v1's rule; if your prints come out heavier, the
empty mass is over the 8.0 kg limit before you start: the cheapest ways to take mass off are listed in [`v2-changelog.md`](v2-changelog.md).

Load paths (hand calculations, `cad-v2/calcs.py`): worst case is the full rover (10.2 kg) with a shock factor of 3, a lateral skid force of 0.6 of the vertical load,
3.6 kg at the drum axis and a 60 N digging reaction at the tooth tip. PETG design stress is 20 MPa in the layer plane and 10 MPa across layers. Each row needs a
safety factor of 2, except the tray plate, which must deflect less than 1 mm at three times the load.

<!-- BEGIN:calcs -->
| Load path | Demand | Capacity | Safety factor | Needed | Inputs |
| :--- | ---: | ---: | ---: | ---: | :--- |
| wheel housing root (bending across layers) | 3.3 | 10 | 3.0 | 2 | Fv N 113, Fl N 68, M N.m 9.25 |
| 608 bearing static load | 365 | 1.29e+03 | 3.5 | 2 | N 365, rating N 1290 |
| M5 T-nut pull-out (mount plate) | 231 | 800 | 3.5 | 2 | N per bolt 231 |
| M8 axle bolt bending | 40.3 | 640 | 15.9 | 2 | M N.mm 2026 |
| pivot bracket wall bearing stress | 9.47 | 20 | 2.1 | 2 | reaction N 306, wall mm 10.0 |
| arm bending at the crossbar (in the layer plane) | 4.92 | 20 | 4.1 | 2 | M N.m 21.7 |
| lift link buckling (2 plates) | 454 | 1.42e+03 | 3.1 | 2 | load N 454, P_cr N 1422 |
| lift link tension | 2.32 | 20 | 8.6 | 2 |  |
| drum torque through the lugs (per rod, N) | 5.65 | 400 | 70.7 | 2 | torque N.m 1.9 |
| M8 rod: friction needed to self-lock (dry brass on steel: 0.15) | 0.0479 | 0.15 | 3.1 | 2 | lead angle deg 3.17 |
| tray plate deflection at 3x load (mm; limit 1) | 0.884 | 1 | 1.1 | 1 | boards g 272, span mm 98, I mm4 316 |
<!-- END:calcs -->

## 9. Measure-first list and known limits

- **Johnson motors:** the gearbox diameter and shaft offset set the four drive cradles, the arm clamp and the lift clamp. Measure one motor and check `JM_*` in `params.py`.
- **Boards and cells:** BTS7960, relay, buck, fuse holders, PZEM-051, battery pack and webcam sizes are listing values (`lib/cots.py`). Board holders are slotted (+-3 mm).
  The battery cradle is sized to the pack: check `BATT` in `modules/electronics.py`.
- **Not modelled:** wiring, connectors, the PZEM shunt, the two lift limit switches, the hook-and-loop strap, thread-locker, the AprilTag stands.
- **Empty mass** is 0.06 kg under the 8.0 kg limit, so it is over the 7.5 kg goal. It also depends on your slicer settings: weigh a wheel.
- **E-stop:** the model has a 60 mm head. The rules ask for at least 40 mm, so any twist-release red mushroom of that size fits the 22.4 mm hole. The tower stands 47 mm from
  the E-stop on its inboard side, so the E-stop can be reached from above, behind and from the outboard side, but not from the tower side.
- **Camera view:** at pan 0 the camera sees the drum and arms (useful) and nothing else; at pan 180 it sees no part of the rover.
- **Sand:** the hood keeps sand off the boards from above; the tray plate is solid, but the underside of the rover is open. Do not drive through deep sand with the hood off.

## 10. Files and how to regenerate

| What | Where |
|---|---|
| Parametric model (every dimension) | `cad-v2/params.py`, modules in `cad-v2/modules/` |
| Print files | `cad-v2/out/stl/*.stl` (43 part types plus the fit-test kit) |
| Whole rover as STEP | `cad-v2/out/rover_v2.step` |
| Interactive viewer (one self-contained file) | `cad-v2/out/rover_v2_viewer.html` |
| Pictures | `docs/img/v2/*.png` |
| Priced bill of materials | `hardware/bom_v2.csv`, `docs/v2-order-list.md` |

```bash
cd cad-v2
uv venv --python 3.12 .venv && source .venv/bin/activate && uv pip install -r requirements.txt
python tasks.py check     # every acceptance check, about 3 minutes
python tasks.py export    # STEP, STLs, BOM (validated in FreeCAD)
python tasks.py render    # viewer and pictures (needs Node and Google Chrome)
python tasks.py docs      # refresh the tables in this guide and the order list
python tasks.py all       # everything
python -m pytest          # 120 tests
```

Change a dimension in `params.py` and run `python tasks.py all`: the model, STLs, BOM, pictures and the tables above all follow. If a check fails,
the message names the parts that clash.

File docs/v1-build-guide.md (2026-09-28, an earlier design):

# Rover v1 — design and build guide

v1 is a small (~7.5 kg) four-wheel rover with a **rotating bucket drum** on a lift
arm. It digs by lowering the spinning drum while creeping forward, carries sand
inside the drum with the arm raised, and dumps by spinning the drum backwards over
the berm target.

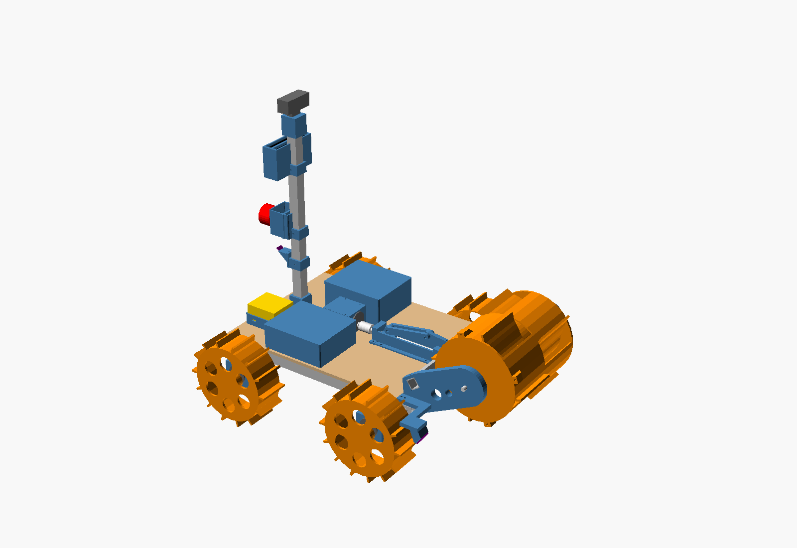
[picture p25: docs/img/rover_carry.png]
Rover v1, carrying

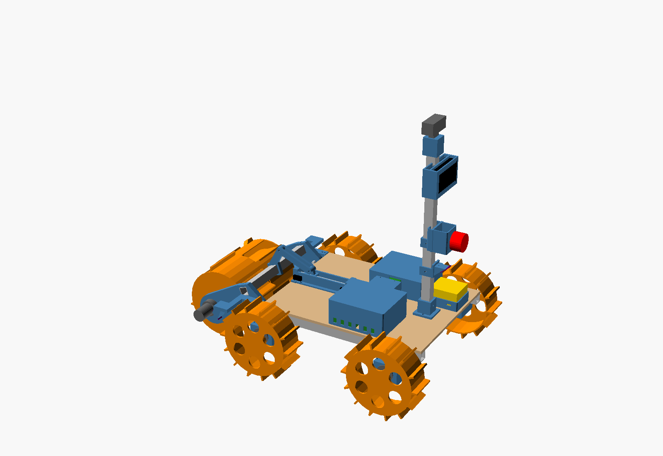
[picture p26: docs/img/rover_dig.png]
Rover v1, digging


## Why a drum (decided 2026-09-28)

- **A light rover can't shove.** A front bucket fills by pushing into the sand, which
  needs traction a ~10 kg rover doesn't have. A drum takes many small bites as it
  spins, so it needs far less push. This is the idea behind NASA's RASSOR.
- **One part digs, carries and dumps.** Spiral baffles inside carry the sand to the
  core; reversing the drum pours it out. No tipping linkage.
- **Proven and printable.** The 2026 Lunabotics champion (UVA) used a rotating drum,
  and a 3D-printed PLA drum dug ~778 kg/h in Tohoku University's sandbox tests.

## Key numbers (from `cad/rover.scad`; mass is an estimate)

| | |
|---|---|
| Stowed size | 632 × 440 × 581 mm (limit 1500 × 750 × 750) |
| Mass | ~7.5 kg empty, ~9.6 kg with a full drum |
| Centre of gravity | 60 % on the front axle empty, 80 % loaded |
| Drum | 160 mm shell, 180 mm over the teeth, 200 mm long, 8 scoops; ~3.6 L gross, ~1.4 L usable |
| Arm range | −25° (pressing in) / −20° (digging, teeth ~8 mm below grade) / +35° (carrying, teeth 111 mm up) |
| Lift actuator | M8 lead screw, 83 mm stroke, ~6 mm/s with a 300 RPM motor, self-locking |
| Ground clearance | ~70 mm under the motor clamps on firm ground |
| Printed parts | 29 part types, ~2.6 kg PETG, all fit a 220 × 220 mm bed, no supports |

## Files

| File | What it is |
|---|---|
| `cad/rover.scad` | Full assembly — open in OpenSCAD. Set `lift` to see other arm poses; the console prints size, mass and CG. |
| `cad/params.scad` | Every shared dimension. Change things here. |
| `cad/wheel.scad`, `drum.scad`, `arm.scad`, `actuator.scad`, `frame.scad`, `electronics.scad` | The parts. |
| `cad/print.scad` + `cad/stl/` | Every printed part in print orientation; STLs ready to slice. |
| `cad/rover_v1.FCStd`, `cad/rover_v1.step.zip` | The assembly for FreeCAD / Onshape / any CAD (mesh-derived, for viewing and measuring). |
| `cad/check_interference.py` | Checks every part group for collisions at four arm angles. Run after any change. |
| `cad/export.py`, `cad/export_freecad.py` | Regenerate the STLs and pictures, and the FreeCAD/STEP files. |

After changing anything: `python3 check_interference.py && python3 export.py`.

## 1. Measure first

The Johnson motor dimensions come from shop listings. Before printing clamps and hubs,
measure one motor and update `params.scad` (`jm_*`): gearbox diameter and length, can
diameter, shaft diameter and flat, shaft length, and **how far the shaft sits off the
gearbox centre** (`jm_shaft_off`). Then print one wheel hub slice to tune `clearance`.

## 2. Cut and drill

20 × 20 × 1.5 mm aluminium square tube (buy a 3 m length):

| Piece | Qty | Length | Holes |
|---|---|---|---|
| Side rail | 2 | 420 mm | Ø8.5 horizontal pivot hole 11 mm from the front end, mid-height. Ø4.5 vertical at 135 and 165 mm from the centre each way (motor clamps). Ø4.5 vertical 26 and 19 mm from the front end (sensor plate). |
| Cross member | 2 | 260 mm | Ø4.5 vertical 10 mm from each end (motor clamps), two Ø4.5 at ±17 mm from the centre on the rear one (mast base). |
| Crossbar | 1 | 256 mm | Ø4.5 vertical 6 mm from each end (arm bolts), one in the centre (lever). |
| Mast | 1 | 380 mm | Ø4.5 cross holes for the base and three collars (drill through the printed parts as a guide). |

Deck: 6 mm plywood, 388 × 300 mm. The front edge stops 32 mm short of the rail ends,
so the drum clears it. Drill through the printed parts as templates.

## 3. Print (PETG, 3–4 walls, 20–25 % gyroid, no supports)

`python3 export.py` prints the list with sizes and estimated grams. Quantities:

| Part | Qty | Notes |
|---|---|---|
| wheel | 4 | Outer face down. |
| drive_clamp_roof / _cap | 4 + 4 | Roof face down; M4 inserts in the roof face. |
| drum_body | 1 | Stands on its end plate, ~196 mm tall; the longest print (~20 h). **Print this first and test it (see §6).** |
| drum_cap, drum_drive_hub | 1 + 1 | Flat. |
| arm_drive, arm_idler | 1 + 1 | Flat; the bearing pocket faces up. |
| lever, pushrod_link | 1 + 2 | Flat. |
| act_channel, act_bearing_block, act_carriage, act_clamp_roof / _floor | 1 + 2 + 1 + 1 + 1 | |
| ebox_base, ebox_lid, driver_hood, battery_tray | 1 each | |
| mast_base, mast_collar_estop / _pzem / _tof, estop_box, pzem_holder, camera_pan_mount | 1 each | |
| tof_plate_left, tof_plate_right, tof_wedge | 1 each | Plates print upside down (flat top on the bed). |
| idler_spacer | 1 | |

## 4. Hardware

- **Bearings:** 5 × 608 (2 arm pivots, 1 drum idler, 2 lead screw).
- **M8:** 1 m threaded rod (cut 173 mm), 2 × M8×50 pivot bolts, 1 × M8×40 idler bolt, ~8 nuts, ~10 washers.
- **M5:** 2 × M5×30 + nylock nuts (pushrod pins).
- **M4:** ~25 × M4×35, ~20 × M4×12–16, 2 × M4×40, 1 × M4×50, nuts and washers. ~30 M4 heat-set inserts.
- **M3:** 20 × M3×45 + nuts (clamp pinch bolts, 4 per clamp); 5 × M3 grub screws + nuts (wheel and drum hubs).
- **Other:** 6 → 8 mm shaft coupler, 2 micro limit switches.

## 5. Assembly order

1. **Frame:** rails + cross members on a flat table. Hang the four drive motors in their
   clamps under the corners, with the shafts pointing outwards and the offset shaft
   **below** the gearbox centre. Bolt deck + rail + clamp together with M4×35 into the inserts.
2. **Wheels:** push onto the D-shafts, tighten the grub screws on the flats.
3. **Actuator:** bearing blocks, channel and motor clamp on the deck centre line. Lock
   the rod to each bearing's inner race with a nut on both sides. Carriage nut drops in
   from the top.
4. **Arms and drum:** press the 608s into the arm roots. Slide the crossbar through both
   arms and bolt it, then add the lever. Bolt the drive hub and cap to the drum. The drum
   motor's gearbox goes through the left arm and is pinched by the M4 bolt; the idler
   side uses the M8 bolt, spacer and cap bearing. Hang the arms on the M8 pivot bolts
   through the rails.
5. **Pushrods:** two links between the carriage ear and the lever with M5 pins. Set the
   limit switches at the ends of travel: arm +35° (up) and −25° (press).
6. **Electronics:** mast base on the rear cross member, collars for the E-stop (≈160 mm
   above the deck), PZEM (≈290 mm, display facing back, high and visible as the rules
   require) and rear ToF. Camera and pan servo on top. ToF plates on the front rail ends.
7. **Power path:** battery → PZEM shunt → E-stop → relay/contactor → main fuse → the
   four BTS7960 drivers and the 5 V buck (Pi 5). Put a fuse on every branch.

## 6. First tests (in this order)

1. **Drum on a stick:** mount the drum + motor on a hand-held jig in the sand pit. Check
   that it fills (~1.4 L) while you drag it forward at ~2–3 cm/s, holds sand when
   lifted, and empties within ~25 s when reversed. Measure the motor current. If it
   stalls, switch to the 10 RPM Johnson (same mount).
2. **Mobility:** chassis + wheels + ~5 kg on board. Drive in loose sand, turn in place,
   and climb out of a dug hole. Try 2–3 grouser variants (`wheel.scad`).
3. **Lift:** actuator + arm with a 3 kg load: full stroke both ways, the limit switches
   work, and the arm holds position with the power off.
4. **Full teleop cycle:** dig → carry → dump, driving from the onboard camera only.

## 7. Known issues and next steps

- **Front-heavy when loaded** (80 % on the front axle): watch for rear-wheel skid when
  turning with a full drum. Carry low, keep the battery rearmost, and consider a small
  rear ballast only if needed (mass costs score).
- **Drum motor torque is the biggest unknown.** It's estimated from papers, not measured.
  Test 1 settles it.
- **Wheels hang on the gearbox shafts** (no outboard bearings in v1). If they wobble or
  wear, set `use_bearing = true` in `wheel.scad` and add outer brackets.
- **Front ToF sensors may see the drum motor in the dig pose.** Mask that zone in
  firmware; they have a clear view while travelling with the drum up.
- **In FreeCAD, the drum object reports "invalid"** (its thin baffles don't survive the
  mesh conversion). It displays and measures fine, but edit the OpenSCAD files, not the
  FreeCAD copy.

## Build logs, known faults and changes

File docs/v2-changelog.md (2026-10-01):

# Rover v2: what changed, and what differs from the spec

Read [`v2-build-guide.md`](v2-build-guide.md) to build it and [`v2-order-list.md`](v2-order-list.md) to buy it. This file is the honest ledger: how v2
compares with v1, where the finished model departs from the approved design spec (`docs/superpowers/specs/2026-09-29-rover-v2-design.md`), and what did not come out
as hoped.

## v1 and v2 side by side

| | v1 (OpenSCAD, 2026-09-28) | v2 (build123d, 2026-09-29) |
|---|---|---|
| Model | mesh-derived STEP, 30 STLs | B-rep STEP (0 invalid shapes in FreeCAD), 43 part types + fit-test kit as watertight STLs |
| Frame | aluminium tube + plywood deck, heat-set inserts | 2020 T-slot, 12 corner brackets, drop-in T-nuts; no drilling, no tapping, no inserts |
| Wheels | cantilevered on the gearbox shaft | two 608 bearings per wheel in a printed housing on the rail, coupler drive |
| Drum | one 490 g piece, about 20 h | 4 rings + 2 plates, largest print 101 g |
| Empty mass, same accounting | about 7.0 kg (its own table says 7.5) | 7.69 kg modelled + 0.25 kg wiring = 7.94 kg |
| Front-axle share, full drum | 80 % | 74 % |
| Cost | INR 22,120 | INR 23,329 (cap 25,000) |
| Printed | 29 types, 2.6 kg | 43 types, 2.55 kg |
| Checks | interference at four arm angles | 120 tests; collisions at five poses, 2 mm sweep clearance, floating hardware, no-support printing, load paths, rules, sensor views, mass and balance |

v2 is about 0.9 kg heavier than v1 on the same accounting. What that buys: bearings on every axle, a covered electronics bay, a proper mast and a real hood. The mass
term of the score scales as 1/mass (the organisers' example: 344.6 of 695 points), so +13 % mass costs about 12 % of that term. The spec budgeted 0.75 kg (11 %); the built rover is 0.95 kg (13 %) above v1.

## Departures from the spec, and why

| Spec said | Built | Why |
|---|---|---|
| Arm poses -25, -20, 0, +20, +35 | -28 (press), -25 (dig), 0, +20, +35 | at -25 the teeth reached only 4 mm below grade; -28 adds a deeper press pose and both are checked |
| Arm pivot at x = 159, z = 145; arm 150 mm | pivot z = 148, arm 156 mm, pivot on two brackets that stand on the rails | the front motor and cradle clashed with the arm at the low poses; the brackets lift the pivot clear |
| T8 x 2 lead screw with a brass flange nut | M8 x 1.25 zinc rod with two brass M8 nuts captured in the carriage | the T8 needs a friction coefficient of about 0.18 to stay put with a safety factor of 2 and brass on steel gives 0.15; the M8 rod locks with a factor of 3 and costs about INR 40 |
| No centre spine | 2020 spine (259 mm) between the cross members | carries the lift channel, the lift motor and the tray's inner edge; also stiffens the frame |
| Rails 380 mm, axles at +-150 | rails 402 mm (x -212 to +190), axles at +150 and -110 (wheelbase 260) | the front bracket ears and cradle bolts need rail under them; the shorter wheelbase moves the loaded front share from 76 % to 74 % |
| Hood: three panels with a raised spine over the lift | two halves split down the centre line, flat roof at z = 196, a two-step port in the front wall for the lift links | a raised spine cannot print roof-down without support; the centre seam also keeps every panel line clear of the vents |
| E-stop on a shelf on the tower | E-stop on its own pedestal left of the tower, panel at z = 251 | the tower's cross-section is 30 x 30; a 60 mm head does not fit on it, and the pedestal keeps the camera view clean |
| E-stop reachable from above, behind and both sides | above, behind and outboard (the tower is 47 mm from the inboard side) | the tower is on the centre line; the rules ask only for a red mushroom of at least 40 mm |
| Tower 280 mm | post 240 mm, camera at 445 mm, PZEM at 321 mm | 31 g and one 40 mm sleeve less; still above the 250 mm the spec wants for the meter |
| Arrow marks as 0.8 mm recesses | three 0.8 mm plates lying on the hood, forward / length / width | a recess in a 1.2 mm roof would cut through it |
| Power bay left, compute bay right | power bay right (next to the battery), compute bay left | shorter power wiring, and it moved the sideways centre of gravity from 12 mm to 7 mm off the centre line |
| Side covers 104 mm | 80 mm, sized to the gap between the wheels | the shorter wheelbase left an 86 mm gap |
| Empty mass budget 7.74 kg, goal 7.5, limit 8.0 | 7.94 kg with the wiring allowance | see below |
| ToF noses on the brackets | ToF boards on 25-degree pads on the pivot brackets | fewer parts; the cone (27 degrees) is checked free at the carry pose |

Also new, not in the spec: a contact-graph check that no fastener floats (it caught four T-nuts hanging off the rail ends), a tray deflection check (0.88 mm at three times the
load, limit 1 mm), and automatic cut-planning of the aluminium into three 1 m bars.

## What did not come out as hoped

- **Mass.** The approved budget was 7.74 kg, the goal 7.5 kg and the limit 8.0 kg. The finished model is 7.94 kg with the wiring allowance: inside the limit by 55 g, 0.44 kg over the goal.
  A lightening pass already took about 0.4 kg off the printed parts (thinner wheel rims and hood walls, pocketed drum plates, a narrower boss on the drum arm, a 2.0 mm tray plate, a 40 mm shorter mast).
  Ways to take off more, cheapest first: drop the two side covers and the three arrow plates (about 45 g with their screws; the arrows can be stickers); drop the two tower sleeves (35 g);
  thin the hood from 1.2 to 1.0 mm (about 25 g); shorten the tower again. Nothing else can go without a redesign.
- **Print weight is a rule of thumb.** Masses follow v1's rule (volume x 1.27 x 0.75). Thin-walled parts print nearly solid, chunky ones lighter, so real prints may differ by a few
  hundred grams either way. Weigh one wheel and one hood half and correct `FILL` in `params.py`.
- **Front-axle share** ended at 74 %, not the spec's 72 %, because the excavator ended up heavier than budgeted. It passes the 75 % limit with 1 point to spare only
  because the rear axle moved forward (with the original wheelbase of 300 mm it was 76 %). The limit is checked at the carry pose, which is how the rover drives when loaded;
  with a full drum and the arm left level it would be 78 %.
- **Cost.** INR 23,329 fits the cap of 25,000 with INR 1,700 to spare. Only the extrusion, the Johnson motors, the BTS7960 drivers, the ToF sensors and the corner brackets are store listings;
  everything else is an estimate (see `v2-order-list.md`). The PZEM-051 is booked at v1's INR 2,000 and is probably cheaper.
- **Not verified by a real print.** Every printability claim is geometric (no overhang steeper than 45 degrees off the bed or a bridge wider than 8 mm). Print the fit-test kit first.

## Open items for the team

1. Print the fit-test kit, set `TOL_BEARING`, `TOL_TRAP`, `TOL_HOLE`; measure one Johnson motor.
2. Order by 5 October (the list is ready).
3. Measure the boards, relay, PZEM and battery when they arrive; update `lib/cots.py` and `BATT`.
4. Mount the two lift limit switches and decide the carriage software limits (working range 20 to 79.5 mm).
5. Decide whether the 0.44 kg over the 7.5 kg goal matters enough to drop the cosmetic parts above.

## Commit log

2026-09-28 Add project context, BOM and README for the CAC 2027 rover
    CONTEXT.md summarises the 2027 rules, scoring, strategy (small ~10 kg
    rover, target 450 autonomy points), system design, ~21k INR budget,
    3D-printing plan, CAD tools, timeline, risks and research notes.
    [bom.csv]
2026-09-28 Add parametric grouser wheel and record free CAD toolchain
    cad/wheel.scad: OpenSCAD wheel (174 mm overall, 60 mm wide, 14 grousers)
    with a 6 mm D-shaft hub for Johnson motors, M3 grub screw + nut slot,
    and an optional outboard 608 bearing pocket. Prints face-down without
    supports.
    CONTEXT.md / README.md: CAD decision is free tools only (FreeCAD 1.1 for
    the assembly, OpenSCAD for parametric parts), with install commands.
    [wheel.scad]
2026-09-28 Add rover v1 CAD: bucket-drum excavator, full assembly and build guide
    v1 is a ~7.5 kg four-wheel rover with a RASSOR-style rotating bucket
    drum on a lead-screw lift arm, chosen after research because a light
    rover can't push a front bucket through loose sand.
    - cad/: parametric OpenSCAD model (params, frame, drum, arm, actuator,
    electronics, full assembly with size/mass/CG report), print layout for
    29 printed parts (STLs in cad/stl, all fit a 220 mm bed, no supports),
    collision checker (clean at -25/-20/0/35 deg), exporters for STL,
    pictures and a FreeCAD/STEP copy of the assembly.
    - docs/v1-build-guide.md: why a drum, key numbers, cut/drill list,
    print list, hardware, assembly o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
    [act_bearing_block.stl, act_carriage.stl, act_channel.stl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]
2026-09-28 Remove stale ToF bracket STL; export.py now deletes STLs no longer in print.scad
    [tof_bracket.stl]
2026-10-01 Add rover v2: parametric CAD, checks, STLs, BOM and docs
    v2 keeps v1's concept (drum digger, four-wheel skid steer) and re-engineers it
    in build123d (cad-v2/): bearing-supported wheels, 2020 T-slot frame with no
    drilling, four-ring drum, M8-rod lift, hooded electronics tray, sensor mast.
    - 120 tests; python tasks.py check passes A1-A10 (collisions at five arm poses,
    2 mm sweep clearance, floating hardware, print without supports, mass,
    balance, rules, sensor views, load paths)
    - 43 printed part types + fit-test kit as STLs, B-rep STEP validated in FreeCAD
    - empty mass 7.94 kg with wiring allowance, front-axle share 74 % full drum,
    cost about INR 23.3k
    - docs/v2-build-guide.md, docs/v2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
    [arm_drive.stl, arm_idler.stl, arm_motor_cap.stl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]
2026-10-01 Design review: encoder motors, 5 A converter, radios-off rule, realistic score estimate
    [bom_v2.csv]
2026-10-01 Move v1/v2 into legacy-v1-v2/, rewrite README, fix paths
    All existing code and docs now live in one folder so new prototype work
    (proto/, firmware/, ros2_ws/) stays separate. No file contents changed
    except path references in README, CONTEXT.md and .gitignore.
    [act_bearing_block.stl, act_carriage.stl, act_channel.stl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]
